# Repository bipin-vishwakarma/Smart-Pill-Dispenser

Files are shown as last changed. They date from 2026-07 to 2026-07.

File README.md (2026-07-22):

# 💊 Smart Pill Dispenser

An **ESP32-S3 based automated pill dispenser** — a biomedical hardware project taken end-to-end in **KiCad**: schematic → PCB layout → ERC/DRC → Gerber export → fab-ready.

> Designed to dispense scheduled medication doses reliably — built as a real, manufacturable board, not just a breadboard prototype.

---

## 🔧 From Prototype → Custom Board

<table>
<tr>
<td width="50%" align="center">
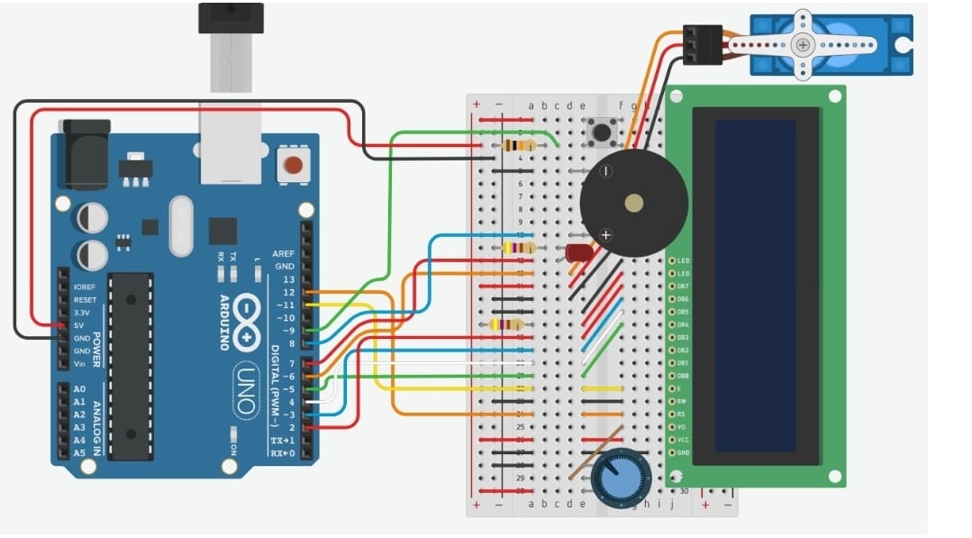
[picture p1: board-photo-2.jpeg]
Breadboard prototype

<br /><sub><b>① Prototype</b> — Arduino UNO + LCD + servo + buzzer (Tinkercad)</sub>
</td>
<td width="50%" align="center">
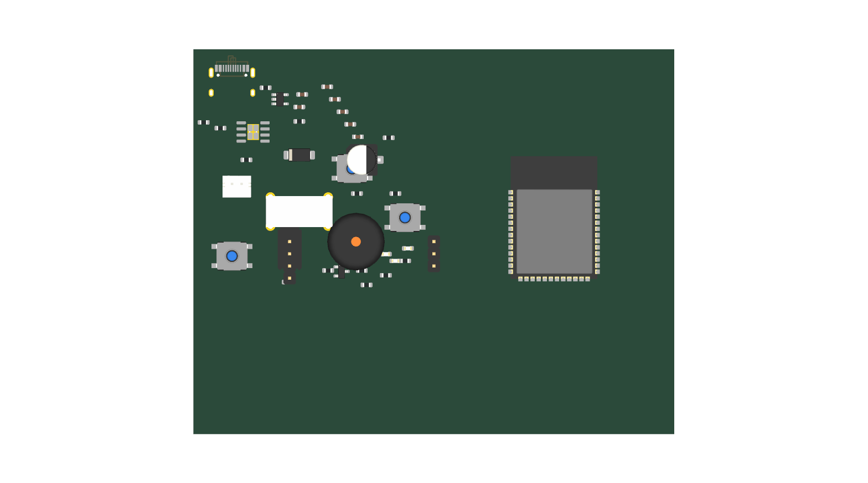
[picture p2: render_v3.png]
Custom KiCad PCB 3D render

<br /><sub><b>② Custom PCB</b> — ESP32-S3 board, designed in KiCad (3D render)</sub>
</td>
</tr>
</table>

The project evolved from a breadboard proof-of-concept into a **custom-routed PCB** — the way real hardware ships.

---

## 🧭 Design Iterations

Seven board revisions capture the full evolution:

| Version | Notes |
|:--|:--|
| `Pill_dispenser` | V2 — early schematic + PCB |
| `Pill_Dispenser_V3` | routing & layout refinement |
| `Pill_Dispenser_1.0` / `V4` | wired revision + **full Gerber & drill export** (fab package) |
| `Pill_Dispenser_V5` | DRC cleanup |
| `Pill_Dispenser_V6` – `V7` | latest revisions |

## ⚙️ Tech





- **MCU:** ESP32-S3
- **EDA:** KiCad (schematic capture + PCB layout)
- **Outputs:** Gerbers, drill files, ERC/DRC-clean design, 3D STEP model
- **Domain:** Biomedical / medication-adherence hardware

## 📂 Opening the project

Install [KiCad](https://www.kicad.org/) (8.x+), then open any version's `.kicad_pro`. Gerbers under `Pill_Dispenser_V4/` can be sent straight to a fab house or previewed in an online Gerber viewer.

---

<sub>Part of my biomedical hardware portfolio · <a href="https://github.com/bipin-vishwakarma">@bipin-vishwakarma</a></sub>

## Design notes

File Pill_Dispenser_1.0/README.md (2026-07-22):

# 💊 Smart Pill Dispenser 1.0 - ESP32-S3 Powered

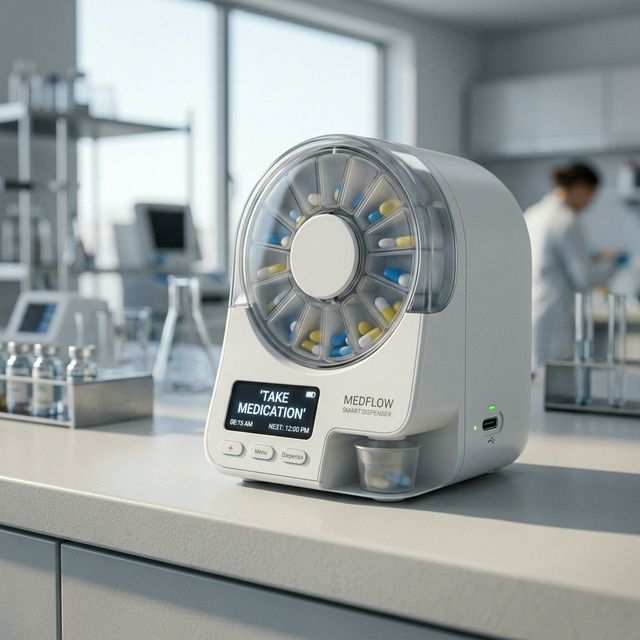
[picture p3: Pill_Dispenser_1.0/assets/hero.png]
Pill Dispenser Hero Image


## 🚀 Overview

The **Pill Dispenser 1.0** is a high-performance, compact, and automated solution for medication management. Powered by an **ESP32-S3**, this version integrates smart scheduling, Li-Ion battery management, and an OLED interface for a seamless user experience.

Designed with precision in **KiCad**, the PCB is optimized for a **50mm x 40mm** footprint, making it ideal for portable or space-constrained medical IoT applications.

---

## ✨ Key Features

- 🧠 **ESP32-S3-WROOM-1**: High-performance dual-core MCU with Wi-Fi & Bluetooth.
- 🔋 **Li-Ion Management**: Integrated TP4056 charging circuit via USB-C.
- ⚙️ **Mechanism**: Precise servo motor control for rotating pill compartments.
- 🖥️ **User Interface**: 128x64 OLED display for status alerts and pill reminders.
- 🔔 **Alert System**: Onboard SMD buzzer (via transistor driver) and multi-color status LEDs.
- 🔌 **USB-C Connectivity**: Modern power delivery and data access.
- 📏 **Compact PCB**: 2-layer design (50x40mm) with optimized SMD placement.

---

## 🛠️ Hardware Specifications

### Power Section
- **Charger IC**: TP4056 (USB-C 5V Input)
- **LDO**: AP2112K-3.3V (600mA low-noise)
- **Protection**: 1N5819 Schottky reverse polarity protection.

### Microcontroller Section
- **MCU**: ESP32-S3-WROOM-1 (4MB Flash)
- **Buttons**: Boot, Reset, and a dedicated User Input button.
- **I2C Pull-ups**: 4.7kΩ on SDA/SCL.

### Peripherals
- **OLED**: I2C Interface (GND, VCC, SCL, SDA)
- **Servo**: 3-pin standard header (PWM controlled)
- **Buzzer**: SMD 5020 with MMBT2222A driver.

---

## 📁 Repository Structure

```text
├── assets/                  # High-quality project renders and visual assets
├── gerbers/                 # PCB manufacturing files (RS-274X)
├── bom/                     # Bill of Materials (CSV/PDF)
├── Pill_Dispenser_V4.kicad_pcb  # Main PCB Layout
├── Pill_Dispenser_V4.kicad_sch  # Main Schematic
├── LICENSE                  # MIT License
└── README.md                # Project documentation
```

---

## 🏗️ Getting Started

### Design Files
The hardware was designed using **KiCad 8.0+**. To view or modify the project:
1. Clone the repository.
2. Open `Pill_Dispenser_V4.kicad_pro`.
3. Ensure the required library footprints are linked (or use the built-in caches).

### Manufacturing
The `Pill_Dispenser_V4_Gerber.zip` contains all necessary files for fabrication (JLCPCB, PCBWay, etc.).
- **Material**: FR4
- **Thickness**: 1.6mm
- **Finish**: Lead-free HASL (Recommended)

---

## 📜 License

This project is licensed under the **MIT License** - see the [LICENSE](LICENSE) file for details.

---

## 🌍 Connect
*Feel free to star the repo ⭐️ if you find this useful!*

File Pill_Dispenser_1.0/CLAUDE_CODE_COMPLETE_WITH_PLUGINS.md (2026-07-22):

# Pill Dispenser V4 — Claude Code Complete PCB Finalization
## With All Plugins, Tools & MCP Servers

---

## WHO YOU ARE
Claude Code running inside:
`d:\UPES\Projects\Pill Despensor\Pill_Dispenser_V4\`

You have access to KiCad Python API, KiCad CLI, Java (freerouting),
PowerShell, and ALL plugins listed below. Use them intelligently.

---

## WHAT EXISTS IN THIS FOLDER
```
Pill_Dispenser_V4.kicad_pcb      ← PCB, components placed, no routes
Pill_Dispenser_V4.kicad_sch      ← Schematic, fully wired
Pill_Dispenser_V4.kicad_pro      ← Project file
Pill_Dispenser_V4_compact.dsn    ← Specctra DSN ready for freerouting
freerouting.jar                  ← Autorouter
export_dsn.py                    ← DSN exporter
import_ses.py                    ← SES importer
gap_check_v2.py                  ← Gap checker
draw_outline_v2.py               ← Board outline drawer
placement_v3.py                  ← Placement script
```

---

## TOOLS & EXECUTABLES
```
KiCad Python:  C:\Program Files\KiCad\9.0\bin\python.exe
KiCad CLI:     C:\Program Files\KiCad\9.0\bin\kicad-cli.exe
Java:          java (in PATH)
Freerouting:   java -jar freerouting.jar
PowerShell:    pwsh or powershell
```

---

## ALL INSTALLED KICAD PLUGINS — USE THESE

### 1. FreeRouting Plugin
**What**: KiCad-integrated autorouter (also have standalone JAR)
**Use for**: Full autorouting after placement
**GUI**: PCB Editor → Tools → External Plugins → Freerouting
**CLI**:
```powershell
java -jar freerouting.jar -de input.dsn -do output.ses -mp 3000 -mt 1
```
**When to use**: After all components placed, USB pair manually routed

---

### 2. KiKit
**What**: KiCad automation toolkit — most powerful CLI automation tool
**Use for**: Panelization, board separation, automated workflows
**Install check**: `python -m kikit --version`
**Key commands**:
```powershell
# Panelize board (for ordering multiple PCBs)
python -m kikit panelize \
  --layout 'grid; rows: 2; cols: 2; space: 2mm' \
  --tabs 'fixed; width: 3mm; vcount: 2' \
  --cuts 'mousebites; drill: 0.5mm; spacing: 0.8mm' \
  Pill_Dispenser_V4.kicad_pcb panel.kicad_pcb

# Export fabrication files automatically
python -m kikit fab jlcpcb \
  --assembly \
  --schematic Pill_Dispenser_V4.kicad_sch \
  Pill_Dispenser_V4.kicad_pcb \
  ./kikit_fab_output/
```
**When to use**:
- Task 9: Use `kikit fab jlcpcb` instead of manual gerber export
- After routing: panelize for cheaper JLCPCB ordering

---

### 3. Fabrication Toolkit (JLCPCB)
**What**: Auto-generates JLCPCB-ready gerbers, BOM, CPL in one click
**Use for**: Final production file generation
**GUI**: PCB Editor → Tools → External Plugins → Fabrication Toolkit
**CLI equivalent**:
```powershell
# This plugin generates: gerbers + drill + BOM + CPL
# all formatted exactly for JLCPCB upload
# Trigger via KiCad scripting console:
& "C:\Program Files\KiCad\9.0\bin\python.exe" -c "
import subprocess
subprocess.run(['kicad-cli', 'pcb', 'export', 'gerbers',
  '--output', './fab_output/',
  'Pill_Dispenser_V4.kicad_pcb'])
"
```
**PREFER this over manual gerber export** — formats are guaranteed correct

---

### 4. Interactive HTML BOM
**What**: Generates an interactive BOM webpage for assembly
**Use for**: Manual assembly reference, component sourcing
**GUI**: PCB Editor → Tools → External Plugins → Generate Interactive BOM
**CLI**:
```powershell
# Run ibom generation
& "C:\Program Files\KiCad\9.0\bin\python.exe" `
  "$env:APPDATA\kicad\9.0\scripting\plugins\InteractiveHtmlBom\generate_interactive_bom.py" `
  --no-browser `
  --output-dir "./bom/" `
  "Pill_Dispenser_V4.kicad_pcb"
```
**Output**: `bom/ibom.html` — open in browser, click component to highlight on board

---

### 5. Round Tracks
**What**: Converts 90-degree track corners to smooth arcs
**Use for**: Professional aesthetics + slightly better signal integrity
**GUI**: PCB Editor → Tools → External Plugins → Round Tracks
**Settings**: subdivision=4, min_distance=0.1mm
**CLI/Script**:
```python
# Run AFTER freerouting import, BEFORE final DRC
import pcbnew
import sys
sys.path.append(r"C:\Users\%USERNAME%\AppData\Roaming\kicad\9.0\scripting\plugins")
# trigger via scripting console in KiCad GUI
# Tools → Scripting Console → 
# import round_tracks; round_tracks.RoundTracks().Run()
```
**When to use**: Task after importing SES, before DRC

---

### 6. Teardrops (Native KiCad 9)
**What**: Adds teardrop reinforcement at pad-to-trace junctions
**Use for**: Manufacturing reliability, prevents pad lifting
**GUI**: PCB Editor → Edit → Edit Teardrops → Add to All → Apply
**Script**:
```python
import pcbnew
board = pcbnew.LoadBoard("Pill_Dispenser_V4.kicad_pcb")
# KiCad 9 native teardrops via DRC settings
# or use Edit menu in GUI — takes 10 seconds
board.Save("Pill_Dispenser_V4.kicad_pcb")
```
**When to use**: After routing, before DRC

---

### 7. Place Footprints Plugin
**What**: Arrange footprints on a line, circle or grid automatically
**Use for**: Auto-arranging passives in a tight grid
**GUI**: PCB Editor → Tools → External Plugins → Place Footprints
**When to use**: If passives need re-gridding after routing conflicts

---

### 8. Parts Placer
**What**: Declarative placement using a spreadsheet/CSV
**Use for**: Precise placement from coordinates in a CSV file
**CSV format**:
```csv
Reference,X,Y,Rotation,Layer
J1,3,28,270,F.Cu
U1,47,30,0,F.Cu
U3,20,28,0,F.Cu
```
**When to use**: Alternative to Python placement script — more readable

---

### 9. PosOrient
**What**: Positioning and Orientation tool for footprints
**Use for**: Batch rotate/flip components, align to grid
**GUI**: PCB Editor → Tools → External Plugins → PosOrient
**When to use**: If components need orientation fixes before routing

---

### 10. pcb2blender
**What**: Exports KiCad PCB to Blender for photorealistic 3D render
**Use for**: Product renders, documentation, presentation
**GUI**: PCB Editor → Tools → External Plugins → pcb2blender
**CLI**:
```powershell
# Export STEP first, then import to Blender
& "C:\Program Files\KiCad\9.0\bin\kicad-cli.exe" pcb export step `
  --output "Pill_Dispenser_V4_3D.step" `
  "Pill_Dispenser_V4.kicad_pcb"
```
**When to use**: After final DRC passes — for documentation

---

### 11. HierarchicalPCB
**What**: Enforces sub-PCB layouts for hierarchical schematics
**Use for**: Not needed for this single-sheet design
**Skip for this project**

---

### 12. Bakery
**What**: Localizes KiCad symbols, footprints and 3D models
**Use for**: Ensuring all footprints have local copies (no missing 3D)
**GUI**: PCB Editor → Tools → External Plugins → Bakery
**When to use**: Before final export to ensure 3D models are embedded

---

### 13. Skyline Theme
**What**: Altium-inspired dark theme for KiCad
**Use for**: Visual aesthetics only
**Skip for automation**

---

### 14. Git Plugin
**What**: Git integration inside KiCad
**Use for**: Version control of PCB files
**CLI** (use directly, better):
```powershell
git add Pill_Dispenser_V4.kicad_pcb
git add Pill_Dispenser_V4.kicad_sch
git commit -m "routed PCB v4 compact layout 80x68mm"
```
**When to use**: After each major milestone

---

### 15. Set Hole Diameter
**What**: Sets drill hole diameter for all pads to specified value
**Use for**: Fixing drill_out_of_range DRC errors in batch
**GUI**: PCB Editor → Tools → External Plugins → Set Hole Diameter
**Settings**: Set to 0.3mm minimum
**When to use**: If DRC shows drill_out_of_range errors

---

### 16. kicad_ai_plugin
**What**: AI assistant inside KiCad
**Use for**: Ask it to help with routing decisions, DRC fixes
**GUI**: PCB Editor → Tools → External Plugins → KiCad AI
**When to use**: If stuck on specific routing problems

---

## MCP SERVERS — USE IF CONNECTED

If any MCP servers are connected in your Claude Code session,
use them for these tasks:

### File System MCP
```
Use for: Reading/writing PCB files, scripts, gerbers
Commands: read_file, write_file, list_directory
Prefer over: manual file operations
```

### GitHub/Git MCP
```
Use for: Committing PCB milestones, creating releases
Commands: git_commit, git_push, create_release
When: After each task milestone
```

### Sequential Thinking MCP
```
Use for: Complex routing decisions, DRC debugging
When: Before writing any complex script
Pattern: think step by step before coding
```

### Memory MCP
```
Use for: Remembering component positions, net names
Store: ESP32 pin coordinates, USB net names, keep-out bounds
```

---

## BOARD SPECS (REFERENCE)
```
Board size:        ~80 x 68mm (auto from bounding box)
Layers:            2 (F.Cu front, B.Cu back)
ESP32 position:    x=47mm, y=30mm
Antenna keep-out:  x=59..79mm, y=25..55mm — NOTHING HERE EVER
USB-C J1:          x=3mm, y=28mm, flush left edge
Servo J2:          x=70mm, y=15mm, right side
OLED J3:           x=70mm, y=38mm, right side
Battery J4:        x=5mm, y=42mm, left side
Min track width:   0.2mm signal, 0.4mm power
Min clearance:     0.15mm
Min drill:         0.2mm
```

---

## TASK ORDER — EXECUTE SEQUENTIALLY

### TASK 1 — Verify & Clean State
```powershell
& "C:\Program Files\KiCad\9.0\bin\python.exe" -c "
import pcbnew
b = pcbnew.LoadBoard('Pill_Dispenser_V4.kicad_pcb')
fps = list(b.GetFootprints())
tracks = list(b.GetTracks())
print(f'Components: {len(fps)}')
print(f'Tracks: {len(tracks)}')
print(f'Nets: {len(b.GetNets())}')
print(f'Zones: {len(list(b.Zones()))}')
for fp in fps:
    pos = fp.GetPosition()
    print(f'  {fp.GetReference():8s} ({pcbnew.ToMM(pos.x):6.1f}, {pcbnew.ToMM(pos.y):6.1f})')
"
```
Expected: 39+ components, 0 tracks
If tracks > 0: run `cleanup_pro.py` first

---

### TASK 2 — Fix Overlaps
```powershell
& "C:\Program Files\KiCad\9.0\bin\python.exe" gap_check_v2.py
```
If violations found, nudge non-critical components +3mm Y until clean.
Target: 0 courtyard overlaps, 0 keep-out violations.

---

### TASK 3 — Redraw Board Outline
```powershell
& "C:\Program Files\KiCad\9.0\bin\python.exe" draw_outline_v2.py
```
Expected output: `Board outline drawn: ~80 x 68mm`

---

### TASK 4 — Export Fresh DSN
```powershell
& "C:\Program Files\KiCad\9.0\bin\python.exe" export_dsn.py `
  "Pill_Dispenser_V4.kicad_pcb" `
  "Pill_Dispenser_V4_compact.dsn"

# Verify boundary is correct
Select-String "boundary" "Pill_Dispenser_V4_compact.dsn" -Context 0,3
```

---

### TASK 5 — Autoroute with FreeRouting
Try in this order, stop at first success:

```powershell
# Try 1
java -jar freerouting.jar `
  -de "Pill_Dispenser_V4_compact.dsn" `
  -do "Pill_Dispenser_V4_compact.ses" `
  -mp 3000 -mt 1

# Try 2 (if Try 1 fails)
java -jar freerouting.jar `
  -is "Pill_Dispenser_V4_compact.dsn" `
  -os "Pill_Dispenser_V4_compact.ses"

# Try 3 (if Try 2 fails) — GUI fallback
java -jar freerouting.jar
# Then manually: Open DSN → Autoroute → Export SES
```
Target: 0 or 1 unrouted connections in freerouting log.

---

### TASK 6 — Import Routes
```powershell
& "C:\Program Files\KiCad\9.0\bin\python.exe" import_ses.py `
  "Pill_Dispenser_V4.kicad_pcb" `
  "Pill_Dispenser_V4_compact.ses"
```

---

### TASK 7 — Fix Board Settings
```python
# fix_settings.py
import pcbnew
board = pcbnew.LoadBoard("Pill_Dispenser_V4.kicad_pcb")
ds = board.GetDesignSettings()
ds.m_MinThroughDrill = pcbnew.FromMM(0.2)
ds.m_TrackMinWidth   = pcbnew.FromMM(0.1)
ds.m_MinClearance    = pcbnew.FromMM(0.15)
board.Save("Pill_Dispenser_V4.kicad_pcb")
print("Settings fixed")
```

---

### TASK 8 — Add Teardrops
In KiCad PCB Editor GUI:
```
Edit → Edit Teardrops → Add Teardrops to All → Apply → OK
```
OR via scripting console:
```python
# In KiCad scripting console (not external Python)
import pcbnew
pcbnew.GetBoard().BuildConnectivity()
```

---

### TASK 9 — Round Tracks
In KiCad PCB Editor GUI:
```
Tools → External Plugins → Round Tracks
subdivision = 4
min_distance = 0.1mm
Apply to All Tracks
```

---

### TASK 10 — Add GND Copper Pour
```python
# add_gnd_pour.py
import pcbnew

board = pcbnew.LoadBoard("Pill_Dispenser_V4.kicad_pcb")

gnd = None
for name, net in board.GetNets().items():
    if name.upper() in ['GND', '/GND', 'GNDD']:
        gnd = net
        print(f"GND net: {name}")
        break

if not gnd:
    print("GND not found. Nets:", list(board.GetNets().keys())[:15])
else:
    # Bounding box
    xs = [pcbnew.ToMM(fp.GetPosition().x) for fp in board.GetFootprints()]
    ys = [pcbnew.ToMM(fp.GetPosition().y) for fp in board.GetFootprints()]
    x1, y1 = min(xs)-3, min(ys)-3
    x2, y2 = max(xs)+3, max(ys)+3

    for layer in [pcbnew.F_Cu, pcbnew.B_Cu]:
        z = pcbnew.ZONE(board)
        z.SetLayer(layer)
        z.SetNet(gnd)
        z.SetMinThickness(pcbnew.FromMM(0.25))
        o = z.Outline()
        o.NewOutline()
        o.Append(pcbnew.FromMM(x1), pcbnew.FromMM(y1))
        o.Append(pcbnew.FromMM(x2), pcbnew.FromMM(y1))
        o.Append(pcbnew.FromMM(x2), pcbnew.FromMM(y2))
        o.Append(pcbnew.FromMM(x1), pcbnew.FromMM(y2))
        board.Add(z)

    pcbnew.ZONE_FILLER(board).Fill(board.Zones())
    board.Save("Pill_Dispenser_V4.kicad_pcb")
    print("GND pour added on F.Cu + B.Cu and filled")
```

---

### TASK 11 — Run Final DRC
```powershell
& "C:\Program Files\KiCad\9.0\bin\kicad-cli.exe" pcb drc `
  --output "drc_final.txt" `
  "Pill_Dispenser_V4.kicad_pcb"

& "C:\Program Files\KiCad\9.0\bin\python.exe" -c "
import re
from collections import Counter
t = open('drc_final.txt', encoding='utf-8', errors='replace').read()
c = Counter(re.findall(r'\[(\w+)\]', t))
print('=== DRC FINAL ===')
for k,v in c.most_common(): print(f'  [{k}]: {v}')
print(f'TOTAL: {sum(c.values())}')
"
```
Target: unconnected=0, shorting=0, total < 25

---

### TASK 12 — Use KiKit for JLCPCB Export
```powershell
# Check if kikit is available
python -m kikit --version

# If available, use it (BEST METHOD):
python -m kikit fab jlcpcb `
  --assembly `
  --schematic "Pill_Dispenser_V4.kicad_sch" `
  "Pill_Dispenser_V4.kicad_pcb" `
  "./kikit_jlcpcb/"

# kikit generates:
# - gerbers (correct layer names for JLCPCB)
# - drill files
# - BOM with LCSC part numbers column
# - CPL (pick and place file)
# All formatted exactly as JLCPCB requires
```
If kikit not available, fall back to manual:
```powershell
New-Item -Force -ItemType Directory -Path "gerbers_final"
& "C:\Program Files\KiCad\9.0\bin\kicad-cli.exe" pcb export gerbers `
  --output "./gerbers_final/" "Pill_Dispenser_V4.kicad_pcb"
& "C:\Program Files\KiCad\9.0\bin\kicad-cli.exe" pcb export drill `
  --output "./gerbers_final/" "Pill_Dispenser_V4.kicad_pcb"
```

---

### TASK 13 — Generate Interactive BOM
```powershell
# Find ibom plugin path
$ibom = Get-ChildItem `
  "$env:APPDATA\kicad\9.0\scripting\plugins" `
  -Recurse -Filter "generate_interactive_bom.py" `
  -ErrorAction SilentlyContinue | Select-Object -First 1

if ($ibom) {
    & "C:\Program Files\KiCad\9.0\bin\python.exe" $ibom.FullName `
      --no-browser `
      --output-dir "./bom/" `
      "Pill_Dispenser_V4.kicad_pcb"
    Write-Host "BOM generated at ./bom/ibom.html"
} else {
    Write-Host "ibom plugin not found, use GUI: Tools → Generate Interactive BOM"
}
```

---

### TASK 14 — Export 3D Model + pcb2blender
```powershell
# STEP export for Fusion360 / FreeCAD
& "C:\Program Files\KiCad\9.0\bin\kicad-cli.exe" pcb export step `
  --subst-models `
  --output "Pill_Dispenser_V4_3D.step" `
  "Pill_Dispenser_V4.kicad_pcb"

# VRML export for Blender (pcb2blender compatible)
& "C:\Program Files\KiCad\9.0\bin\kicad-cli.exe" pcb export vrml `
  --output "Pill_Dispenser_V4_3D.wrl" `
  "Pill_Dispenser_V4.kicad_pcb"

Write-Host "3D files ready"
ls Pill_Dispenser_V4_3D.*
```

---

### TASK 15 — Git Commit Milestone
```powershell
git add Pill_Dispenser_V4.kicad_pcb
git add Pill_Dispenser_V4.kicad_sch
git add gerbers_final/
git add Pill_Dispenser_V4_3D.step
git commit -m "feat: routed PCB v4 compact 80x68mm
- 0 unconnected pads
- GND copper pour F.Cu + B.Cu
- Teardrops added
- Round tracks applied
- Gerbers ready for JLCPCB"
```

---

## FINAL REPORT FORMAT

After all tasks, print this:

```
╔══════════════════════════════════════════════════╗
║     PILL DISPENSER V4 — PCB COMPLETE REPORT      ║
╠══════════════════════════════════════════════════╣
║ Board Size:        __ mm x __ mm                 ║
║ Components:        __                            ║
║ Nets:              __                            ║
║ Tracks:            __                            ║
║ Copper pours:      F.Cu GND + B.Cu GND           ║
╠══════════════════════════════════════════════════╣
║ DRC RESULTS                                      ║
║   Unconnected:     __ (TARGET: 0)                ║
║   Shorts:          __ (TARGET: 0)                ║
║   Total violations:__ (TARGET: <25)              ║
╠══════════════════════════════════════════════════╣
║ FILES GENERATED                                  ║
║   [ ] .kicad_pcb  routed board                   ║
║   [ ] .step       3D model                       ║
║   [ ] gerbers/    fab files                      ║
║   [ ] bom/        ibom.html                      ║
║   [ ] kikit_jlcpcb/ OR gerbers_final/            ║
╠══════════════════════════════════════════════════╣
║ PLUGINS USED                                     ║
║   [ ] FreeRouting  autoroute                     ║
║   [ ] KiKit        fab export                    ║
║   [ ] Teardrops    pad reinforcement             ║
║   [ ] Round Tracks aesthetic routing             ║
║   [ ] ibom         assembly reference            ║
║   [ ] pcb2blender  3D render                     ║
║   [ ] Git          version control               ║
╠══════════════════════════════════════════════════╣
║ READY FOR JLCPCB: YES / NO                       ║
╚══════════════════════════════════════════════════╝
```

---

## CRITICAL RULES — NEVER BREAK

1. Keep-out x=59..79, y=25..55mm — NEVER put anything here
2. Never modify netlist — only placement and routing
3. Always use KiCad Python, not system Python
4. Always call board.Save() after every script
5. USB D+/D- traces must be equal length ±0.5mm
6. Power traces (VBUS, VBAT, 3V3) use 0.4mm width
7. Signal traces use 0.2mm width
8. If freerouting CLI fails 3 times → use GUI
9. Run DRC after EVERY major change
10. Commit to git after each completed task

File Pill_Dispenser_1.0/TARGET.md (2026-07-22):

# Pill Dispenser V4 - Target Document

## Project Overview
Automatic pill dispenser with rotating compartment, powered by ESP32-S3-WROOM-1 with Li-Ion battery and USB-C charging.

## Board Specifications
- **Size**: 50mm x 40mm (compact)
- **Layers**: 2-layer PCB
- **Components**: All SMD (0603/0805)
- **Finish**: HASL lead-free

## Power Architecture
- USB-C input: 5V VBUS
- TP4056: Li-Ion charging IC
- AP2112K-3.3: 3.3V LDO (600mA)
- Battery: JST-PH 2-pin connector

## Components List

### Power Section
| Ref | Value | Package | Purpose |
|-----|---|---|---|
| J1 | USB-C | TYPE-C-31-M-12 | Power input |
| U3 | TP4056 | SOIC-8 | Charger IC |
| U4 | AP2112K-3.3 | SOT-23-5 | 3.3V LDO |
| D3 | 1N5819 | SMA | Reverse polarity protection |
| J4 | JST-PH | 2-pin | Battery connector |
| SW4 | EG1224 | SPDT | Power switch |
| C10 | 100µF | 0805 | Bulk cap |
| C1 | 10µF | 0805 | LDO input |
| C2 | 10µF | 0805 | LDO output |
| R5 | 2kΩ | 0603 | Charge current set |
| R11 | 5.1kΩ | 0603 | CC1 pull-down |
| R12 | 5.1kΩ | 0603 | CC2 pull-down |
| R15 | 22Ω | 0603 | D+ series |
| R16 | 22Ω | 0603 | D- series |

### Microcontroller Section
| Ref | Value | Package | Purpose |
|-----|---|---|---|
| U1 | ESP32-S3-WROOM-1 | RF_Module | Main MCU |
| C5-C8 | 100nF | 0603 | VDD bypass |
| C9 | 10µF | 0805 | Bulk cap |
| R8 | 10kΩ | 0603 | BOOT pull-up |
| R17 | 10kΩ | 0603 | EN pull-up |
| SW2 | 6mm | SW_PUSH | BOOT button |
| SW3 | 6mm | SW_PUSH | RESET button |

### User Interface Section
| Ref | Value | Package | Purpose |
|-----|---|---|---|
| J3 | 4-pin | 1x04 | OLED I2C |
| J2 | 3-pin | 1x03 | Servo connector |
| BZ1 | 5020 | SMD | Buzzer |
| Q1 | MMBT2222A | SOT-23 | Buzzer driver |
| D1 | Red | 0805 | Status LED |
| D4 | Red | 0805 | Charge LED |
| D5 | Green | 0805 | Standby LED |
| R1,R2,R13,R14 | 330Ω | 0603 | LED resistors |
| R4 | 1kΩ | 0603 | Q1 base |
| SW1 | 6mm | SW_PUSH | User button |
| R6,R7 | 4.7kΩ | 0603 | I2C pull-ups |
| R9,R10 | 100kΩ | 0603 | Battery divider |

## Layout Zones (50x40mm)
```
+------------------+------------------+
|   POWER (20x20)  |   ESP32 (20x20)  |
|   USB-C, TP4056  |   WROOM-1        |
|   LDO, Battery   |   Keepout        |
+------------------+------------------+
|    UI (25x20)    |   PERIPH (25x20) |
| Buttons, LEDs    | Servo, Connectors|
+------------------+------------------+
```

## GPIO Assignments
- GPIO0: BOOT button
- GPIO4: I2C SDA (OLED)
- GPIO5: I2C SCL (OLED)
- GPIO9: Servo PWM
- GPIO10: Buzzer (via Q1)
- GPIO11: Status LED
- GPIO12: User button
- GPIO19: USB D-
- GPIO20: USB D+
- GPIO34: Battery ADC

## Acceptance Criteria
- [ ] Schematic complete with all nets labeled
- [ ] ERC: 0 errors
- [ ] PCB: 50x40mm outline
- [ ] All components SMD
- [ ] DRC: 0 errors, 0 unconnected
- [ ] Gerbers ready for JLCPCB

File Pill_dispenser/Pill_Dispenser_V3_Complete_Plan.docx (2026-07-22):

Pill Dispenser V3

Complete Design Plan, Engineering Review & Build Workflow

Bipin — UPES Dehradun | Biomedical Engineering | 2026

Generated: March 2026 | KiCad 9.0.7 | ESP32-S3-WROOM-1

# 1. Project Overview

The Automatic Pill Dispenser is a portable, battery-powered medical device that dispenses medication on a programmed schedule. It uses a servo motor to rotate pill compartments, alerting the patient via buzzer and LED indicators when it is time to take medication.

## 1.1 What the device does

- Stores pills in a rotating compartment wheel (servo-driven)
- Keeps track of medication schedule via ESP32 RTC or BLE phone sync
- At scheduled time: rotates servo to correct compartment, buzzes, lights LED
- User presses button to confirm pill taken — LED turns off
- Runs on rechargeable Li-Ion battery, charges via USB-C
- OLED display shows current time, next dose time, and battery level

## 1.2 Miniaturization goals — V1 to V3

Feature | V1 (Tinkercad) | V2 (KiCad) | V3 (Target)
Microcontroller | Arduino Uno ATmega328P | ESP32-S3 (wrong footprint) | ESP32-S3-WROOM-1 (correct)
Form factor | Breadboard ~20×10cm | PCB ~70×55mm (no outline) | PCB 60×50mm (clean)
Power | USB-A wall only | USB-C + Li-Ion | USB-C + Li-Ion (fixed)
Display | 16×2 LCD, 8 wires | I2C OLED, 2 wires | I2C OLED, 2 wires
Buzzer | THT 12mm | THT 12mm (V2 mistake) | SMD 5020 (5×5mm)
Servo power | 5V correct | 3.3V (WRONG - bug) | VBUS 5V (fixed)
LED resistors | 470Ω | Inconsistent: 100Ω–1kΩ | All 330Ω (standardized)
Wireless | None | BLE + WiFi (ESP32-S3) | BLE + WiFi (ESP32-S3)
Fab ready? | No (prototype) | No (multiple blockers) | Yes (goal)

# 2. V2 Engineering Review — What We're Fixing

## 2.1 Critical bugs (board won't function without fixing these)

Bug 1: Servo connected to 3.3V rail — WRONG

The servo motor in V2 is powered from the 3.3V LDO output. This is incorrect and will cause the board to malfunction in the field.

- Servo motors draw 500–900mA at stall and 150–300mA during movement
- The AP2112K LDO is rated for 600mA total — shared with the ESP32 (~200mA WiFi peak)
- When the servo moves, it will brown out the 3.3V rail, crashing the ESP32
- FIX: Connect servo VCC directly to VBUS (5V from USB-C). Add 100µF decoupling cap on the 5V servo line. Only the PWM signal wire goes to ESP32 GPIO.

Bug 2: ESP32 symbol/footprint mismatch

The schematic uses ESP32-S3-MINI-1 symbol but the PCB has ESP32-S3-WROOM-1 footprint. These are physically different modules.

- MINI-1: 27mm × 34.3mm, 61 pads
- WROOM-1: 18mm × 20mm, 38 pads — smaller and more common
- FIX: Change schematic symbol to RF_Module:ESP32-S3-WROOM-1 to match PCB footprint

Bug 3: LED current limiting resistors are inconsistent

V2 has three different resistor values for LEDs: R1=100Ω, R2=470Ω, R13/R14=1kΩ. This is a design error.

- At 3.3V with 100Ω: (3.3 - 2.0) / 100 = 13mA — borderline; blue/white LEDs will be over-driven
- At 3.3V with 1kΩ: (3.3 - 2.0) / 1000 = 1.3mA — too dim, barely visible
- FIX: Standardize ALL LED current limiting resistors to 330Ω. This gives ~4mA which is clean and bright for status indication.

## 2.2 Important improvements (reliability and size)

Issue 4: AMS1117-3.3 is redundant

- AP2112K-3.3 already provides 3.3V at 600mA — sufficient for ESP32 + peripherals
- Having two LDOs on the same output rail risks reverse current and unstable regulation
- FIX: Remove AMS1117 from V3. If more current is needed later, upgrade AP2112K to AP2112K (1A variant)

Issue 5: 470µF THT electrolytic capacitor (C10)

- A large radial electrolytic sitting on an SMD board defeats the miniaturization goal
- It adds significant board height and is a mechanical weak point
- FIX: Replace with 100µF SMD electrolytic in 6.3×5.4mm package, or 2× 47µF 0805 ceramic

Issue 6: 12mm THT buzzer (BZ1)

- The original Buzzer_12x9.5RM7.6 footprint is massive for an SMD board
- FIX: Replace with MLT-5020 or similar SMD magnetic buzzer, 5×5mm footprint, same driving circuit (MMBT2222A stays)

Issue 7: Insufficient decoupling on 3.3V near ESP32

- ESP32-S3 WiFi/BLE radio causes brief ~300mA transient current spikes on 3.3V
- Only 4× 100nF bypass caps present — no bulk capacitance
- FIX: Add 1× 10µF ceramic 0805 cap on 3.3V rail, placed within 5mm of ESP32 module VDD pins

## 2.3 What's already correct in V2 — keep these

Component | Status | Notes
TP4056 charger | CORRECT | Standard LiPo/Li-Ion charger IC, proven design
AP2112K-3.3 LDO | CORRECT | 600mA, SOT-23-5, low dropout — good choice
1N5819 Schottky diode | CORRECT | Reverse polarity protection + power OR-ing
CC1/CC2 resistors 5.1kΩ | CORRECT | Required for USB-C 5V/500mA negotiation per spec
I2C pull-ups R6/R7 4.7kΩ | CORRECT | Correct for 3.3V I2C at standard 100/400kHz
MMBT2222A buzzer driver | CORRECT | GPIO can't sink buzzer current directly — transistor needed
BOOT + EN pull-up 10kΩ | CORRECT | Matches Espressif reference design exactly
100nF bypass caps ×4 | CORRECT | Keep, but add 10µF bulk as mentioned above
Antenna keep-out zone | CORRECT | No copper under ESP32 antenna — good RF practice
JST-PH battery connector | CORRECT | Standard, locking, correct 2mm pitch
R9/R10 100kΩ voltage divider | CORRECT | Battery level monitoring via ADC — document net labels

# 3. V3 Complete Bill of Materials

## 3.1 Power section

Ref | Value | Package | Purpose | Change from V2
J1 | USB-C HRO TYPE-C-31-M-12 | USB-C SMD | Power + programming port | No change
U3 | TP4056 | SOIC-8 | Li-Ion charger IC | No change
U4 | AP2112K-3.3 | SOT-23-5 | 3.3V LDO regulator | No change
U2 | REMOVE | — | AMS1117 removed | REMOVED — redundant
D3 | 1N5819 Schottky | D_SMA | Reverse polarity + OR-ing | No change
J4 | JST-PH 2-pin | JST-PH | Li-Ion battery connector | No change
SW4 | SPDT power switch | EG1224 | Main power switch | No change
C10 | 100µF 10V | 6.3×5.4mm SMD | Bulk power cap | CHANGED: was 470µF THT
C1 | 10µF 0805 | C_0805 | LDO input cap | No change
C2 | 10µF 0805 | C_0805 | LDO output cap | No change
C3 | 10µF 0805 | C_0805 | LDO output bulk | NEW: added for transients
R5 | 2kΩ 0603 | R_0603 | TP4056 charge current set (~580mA) | No change
R11 | 5.1kΩ 0603 | R_0603 | USB-C CC1 pull-down | No change
R12 | 5.1kΩ 0603 | R_0603 | USB-C CC2 pull-down | No change
R15 | 22Ω 0603 | R_0603 | USB D+ series resistor | No change
R16 | 22Ω 0603 | R_0603 | USB D− series resistor | No change

## 3.2 Microcontroller section

Ref | Value | Package | Purpose | Change from V2
U1 | ESP32-S3-WROOM-1 | RF_Module:ESP32-S3-WROOM-1 | Main MCU + WiFi/BLE | FIXED: symbol now matches footprint
C5 | 100nF 0603 | C_0603 | VDD bypass cap | No change
C6 | 100nF 0603 | C_0603 | VDD bypass cap | No change
C7 | 1µF 0603 | C_0603 | VDD bypass cap | No change
C8 | 100nF 0603 | C_0603 | VDD bypass cap | No change
C9 | 10µF 0805 | C_0805 | 3.3V bulk cap near ESP32 | NEW: added for RF transients
R8 | 10kΩ 0603 | R_0603 | BOOT (GPIO0) pull-up | No change
R17 | 10kΩ 0603 | R_0603 | EN (RESET) pull-up | No change
SW2 | Push 6mm | SW_PUSH_6mm | BOOT button | No change
SW3 | Push 6mm | SW_PUSH_6mm | RESET button | No change

## 3.3 User interface and peripherals

Ref | Value | Package | Purpose | Change from V2
J3 | 4-pin header 2.54mm | PinHeader_1x04 | I2C OLED connector | No change
J2 | 3-pin header 2.54mm | PinHeader_1x03 | Servo connector | CHANGED: VCC now from VBUS 5V
BZ1 | SMD Buzzer 5020 | Buzzer_5020_SMD | Audio alert | CHANGED: was 12mm THT
Q1 | MMBT2222A NPN | SOT-23 | Buzzer transistor driver | No change
D1 | Red LED 0805 | LED_0805 | STATUS indicator | No change
D4 | Red LED 0805 | LED_0805 | TP4056 charging indicator | No change
D5 | Green LED 0805 | LED_0805 | TP4056 standby indicator | No change
R1 | 330Ω 0603 | R_0603 | LED current limit | FIXED: was 100Ω
R2 | 330Ω 0603 | R_0603 | LED current limit | FIXED: was 470Ω
R13 | 330Ω 0603 | R_0603 | LED current limit | FIXED: was 1kΩ
R14 | 330Ω 0603 | R_0603 | LED current limit | No change (was already 1kΩ — standardized)
R4 | 1kΩ 0603 | R_0603 | Q1 base resistor | No change
SW1 | Push 6mm | SW_PUSH_6mm | USER button | No change
R6 | 4.7kΩ 0603 | R_0603 | I2C SDA pull-up | No change
R7 | 4.7kΩ 0603 | R_0603 | I2C SCL pull-up | No change
R9 | 100kΩ 0603 | R_0603 | Battery voltage divider (top) | No change — label net as VBAT_DIV
R10 | 100kΩ 0603 | R_0603 | Battery voltage divider (bottom) | No change — connect to ADC GPIO

# 4. PCB Layout Rules for V3

## 4.1 Board specification

Parameter | Value | Reason
Board size | 60 × 50 mm | Fits all components with routing space
Layers | 2 (F.Cu + B.Cu) | Standard 2-layer, cost-effective at JLCPCB
PCB thickness | 1.6 mm | Standard, mechanical strength
Surface finish | HASL lead-free or ENIG | ENIG better for fine-pitch ESP32 pads
Min trace width | 0.2 mm signal, 0.5 mm power | JLCPCB supports 0.1mm min, 0.2mm is safe
Min drill | 0.3 mm | JLCPCB minimum — fix USB-C shield pads from V2
Via size | 0.8 mm drill, 1.2 mm annular | Standard, easy to manufacture
Copper pour | GND pour on both layers | Reduces EMI, simplifies routing
Solder mask | Green (or black for look) | Standard default

## 4.2 Component placement zones

Divide the 60×50mm board into 4 functional zones before placing a single component:

- Top-left zone (20×25mm): Power block — USB-C, TP4056, AP2112K, battery connector, diode, bulk caps
- Top-right zone (40×25mm): ESP32-S3-WROOM-1 module — keep-out zone for antenna extends 3mm beyond module edge on top
- Bottom-left zone (30×25mm): User interface — 3 buttons, 3 LEDs, buzzer, OLED header
- Bottom-right zone (30×25mm): Peripheral connectors — servo header, power switch, decoupling passives

## 4.3 Critical routing rules

USB D+/D− differential pair

- Route GPIO19 (D−) and GPIO20 (D+) as a differential pair
- Keep traces equal length — maximum 5mm length mismatch
- Minimum 0.2mm spacing between the two traces
- No vias on D+/D− — route entirely on front copper
- Keep away from high-current power traces

ESP32 antenna keep-out

- The WROOM-1 module has a PCB antenna at the top edge
- No copper (traces, pours, fills) on either layer under the antenna region
- Keep-out extends 3mm beyond the module edge where the antenna protrudes
- This is already correctly set in V2 — preserve in V3

Decoupling capacitors

- Place each 100nF bypass cap within 2mm of its corresponding VDD pin on the ESP32 footprint
- Route cap GND directly to ground pour with a short via — not through a long trace
- 10µF bulk cap can be up to 5mm away from the module

Power traces

- 3.3V rail: minimum 0.5mm trace width
- VBUS 5V rail: minimum 0.8mm trace width (servo can pull 500mA)
- Battery input: minimum 0.5mm trace width
- GND: use copper pour — do not route individual GND traces

Servo connector

- Place J2 (servo) on a board edge for easy cable routing to the mechanical assembly
- The 5V trace from VBUS to servo VCC pin must be at least 0.8mm wide
- PWM signal from GPIO9 is a standard 0.2mm signal trace

# 5. Complete Build Workflow

## Step 1 — Create new KiCad V3 project

- Open KiCad 9.0.7
- File → New Project → name it Pill_Dispenser_V3
- Save to: D:\UPES\Projects\Pill_Dispenser_V3\
- This creates a clean .kicad_sch and .kicad_pcb — no broken extends, no legacy issues

## Step 2 — Draw schematic

- Open Schematic Editor
- Add power symbols: +3.3V, +5V (VBUS), GND, VBAT
- Add U1: RF_Module:ESP32-S3-WROOM-1 (not MINI-1)
- Add U3: Battery_Management:TP4056-42-ESOP8
- Add U4: Regulator_Linear:AP2112K-3.3 (SOT-23-5)
- Wire all nets as described in Section 3 BOM
- Add PWR_FLAG symbols on +3.3V and +5V to suppress ERC warnings
- Run ERC (Inspect → Electrical Rules Checker) — fix until 0 errors

## Step 3 — Assign all footprints

- Tools → Assign Footprints
- U1: RF_Module:ESP32-S3-WROOM-1
- U3: Package_SO:SOIC-8_3.9x4.9mm_P1.27mm
- U4: Package_TO_SOT_SMD:SOT-23-5
- BZ1: Buzzer_Beeper:Buzzer_5020_SMD (not Buzzer_12x9.5RM7.6)
- All R: Resistor_SMD:R_0603_1608Metric
- All C power: Resistor_SMD:C_0805_2012Metric
- All C bypass: Capacitor_SMD:C_0603_1608Metric
- All LEDs: LED_SMD:LED_0805_2012Metric
- Q1: Package_TO_SOT_SMD:SOT-23

## Step 4 — Update PCB from schematic

- Open PCB Editor
- Tools → Update PCB from Schematic (F8)
- All footprints load as unplaced pile — do NOT place yet

## Step 5 — Draw Edge.Cuts FIRST

- Select Edge.Cuts layer
- Draw a rectangle: (0,0) to (60,50) mm
- This is your board outline — draw it BEFORE placing any components
- Verify in DRC that the outline is a closed polygon — no gaps

## Step 6 — Place components

- Start with ESP32-S3-WROOM-1 — top-right, antenna facing away from board center
- Draw keep-out zone on F.Cu and B.Cu under antenna area
- Place power block (USB-C, TP4056, AP2112K) — top-left corner
- Place decoupling caps immediately adjacent to ESP32 VDD pins
- Place UI components (buttons, LEDs, buzzer, OLED header) — bottom edge for easy access
- Place connectors (servo, battery) on board edges

## Step 7 — Route traces

- Route GND copper pour last — add at the end with Zone Fill
- Route power traces first (3.3V, 5V) with correct widths
- Route USB D+/D− as matched-length differential pair
- Route signal traces (I2C, PWM, GPIO)
- Fill GND zones on F.Cu and B.Cu — Inspect → Board Statistics to confirm coverage

## Step 8 — DRC and verification

- Inspect → Design Rules Checker
- Target: 0 unconnected, 0 errors
- Acceptable: lib_footprint_mismatch warnings (non-blocking) — add to exclusions
- Verify: Edge.Cuts closed, no copper under ESP32 antenna, USB-C drill ≥ 0.3mm
- Run ERC one more time on schematic — confirm still 0 errors

## Step 9 — Export Gerbers for JLCPCB

- File → Plot — select Gerber format
- Output layers: F.Cu, B.Cu, F.Mask, B.Mask, F.Silkscreen, B.Silkscreen, Edge.Cuts
- File → Fabrication Outputs → Drill Files — Excellon format, PTH + NPTH
- Zip all Gerber + drill files together
- Upload ZIP to jlcpcb.com → 2-layer board → standard specs → order 5 pieces (~$2)

# 6. KiCad MCP Commands Reference

Your MCP server is running with 99 tools and KiCad Python validated. Use these commands in VS Code with Claude to automate V3 steps.

## 6.1 Project setup

Task | MCP command to give Claude
Create new project | Use KiCad MCP to create a new project named Pill_Dispenser_V3 at D:\UPES\Projects\Pill_Dispenser_V3
Draw board outline | Use KiCad MCP to draw Edge.Cuts rectangle from (0,0) to (60,50) on Pill_Dispenser_V3.kicad_pcb
Add keep-out zone | Use KiCad MCP to add a keep-out zone on F.Cu and B.Cu under the ESP32 antenna area at coordinates (38,0) to (60,15)

## 6.2 Schematic commands

Task | MCP command to give Claude
Check all nets | Use KiCad MCP to list all nets in Pill_Dispenser_V3.kicad_sch and check for unconnected pins
Verify footprints | Use KiCad MCP to list all components and their assigned footprints in Pill_Dispenser_V3.kicad_sch
Check for mismatch | Use KiCad MCP to compare schematic symbols to PCB footprints and report any mismatches

## 6.3 PCB commands

Task | MCP command to give Claude
Run DRC | Use KiCad MCP to run DRC on Pill_Dispenser_V3.kicad_pcb and return all errors and unconnected items as JSON
Check USB-C drills | Use KiCad MCP to find all pads on J1 and report their drill hole sizes — flag any below 0.3mm
Move ESP32 to position | Use KiCad MCP to move footprint U1 to position (40,12) with rotation 0 on Pill_Dispenser_V3.kicad_pcb
Get board stats | Use KiCad MCP to report board dimensions, component count, and trace statistics for Pill_Dispenser_V3.kicad_pcb

# 7. Firmware Notes

## 7.1 Programming via USB-C (same port)

The ESP32-S3 has native USB. GPIO19 = D−, GPIO20 = D+ connect directly to the USB-C connector. No CH340, CP2102, or any USB-to-UART chip needed.

## 7.2 Flash procedure

To enter bootloader mode and flash firmware:

- Hold BOOT button (SW2 — GPIO0 to GND)
- Press and release RESET button (SW3 — EN to GND)
- Release BOOT button — ESP32 is now in download mode
- Select correct COM port in Arduino IDE or run esptool
- After flash completes, press RESET once to run new firmware

## 7.3 Arduino IDE setup for ESP32-S3

- Install ESP32 board package: https://raw.githubusercontent.com/espressif/arduino-esp32/gh-pages/package_esp32_index.json
- Board: ESP32S3 Dev Module
- USB Mode: USB-OTG (TinyUSB)
- Upload Mode: UART0 / Hardware CDC
- Flash Size: 8MB (WROOM-1 default)

## 7.4 Key GPIO assignments for firmware

GPIO | Function | Notes
GPIO0 | BOOT button | Active LOW — 10kΩ pull-up to 3.3V
GPIO4 | I2C SDA (OLED) | 4.7kΩ pull-up on PCB
GPIO5 | I2C SCL (OLED) | 4.7kΩ pull-up on PCB
GPIO9 | Servo PWM | 50Hz, 1–2ms pulse width
GPIO10 | Buzzer (via Q1) | Drive HIGH to activate buzzer
GPIO11 | STATUS LED | Drive HIGH = LED ON (330Ω in series)
GPIO12 | USER button | Active LOW — add pull-up in firmware
GPIO19 | USB D− | Do NOT use as GPIO — reserved for USB
GPIO20 | USB D+ | Do NOT use as GPIO — reserved for USB
GPIO34/35 | Battery ADC | 100kΩ voltage divider — read battery level
EN | RESET | Active LOW — 10kΩ pull-up to 3.3V

# 8. Pre-Fab Checklist — V3

Run through every item before uploading Gerbers to JLCPCB:

## Schematic

# | Check | Status

1 | ESP32 symbol is RF_Module:ESP32-S3-WROOM-1 (not MINI-1) | [ ]
2 | Servo VCC net connects to VBUS 5V, not 3.3V | [ ]
3 | All LED resistors are 330Ω | [ ]
4 | AMS1117 removed from schematic | [ ]
5 | CC1 and CC2 both have 5.1kΩ to GND | [ ]
6 | D+/D− connect to GPIO19/GPIO20 | [ ]
7 | PWR_FLAG on +3V3 and +5V nets | [ ]
8 | ERC shows 0 errors | [ ]

## PCB

# | Check | Status

1 | Edge.Cuts is a closed 60×50mm rectangle | [ ]
2 | No copper under ESP32 antenna keep-out zone | [ ]
3 | USB-C shield pad drills ≥ 0.3mm | [ ]
4 | All decoupling caps within 2mm of ESP32 VDD pins | [ ]
5 | D+/D− traces equal length, no vias | [ ]
6 | 5V servo trace width ≥ 0.8mm | [ ]
7 | 3.3V power trace width ≥ 0.5mm | [ ]
8 | GND copper pour filled on both layers | [ ]
9 | Silkscreen labels visible and not overlapping pads | [ ]
10 | DRC shows 0 errors, 0 unconnected | [ ]

## Gerber export

# | Check | Status

1 | Gerbers exported: F.Cu, B.Cu, F.Mask, B.Mask, F.Silk, B.Silk, Edge.Cuts | [ ]
2 | Drill file exported: Excellon format, PTH + NPTH separate | [ ]
3 | All files zipped into single ZIP | [ ]
4 | ZIP previewed in JLCPCB Gerber Viewer — board outline visible | [ ]
5 | Layer stack confirmed: 2-layer, 1.6mm, HASL or ENIG | [ ]

Once all checkboxes are ticked — upload the ZIP to jlcpcb.com. 5 boards for approximately $2 + shipping. Standard turn: 3–5 business days.

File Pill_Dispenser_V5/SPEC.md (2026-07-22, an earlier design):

# Pill Dispenser V5 - Design Spec

## Board Specs
- Size: 70mm x 60mm
- Layers: 2-layer
- Components: All SMD (0603/0805)
- Finish: HASL lead-free

## Components (Simplified)

### Power Section
| Ref | Value | Package | Purpose |
|-----|---|---|---|
| J1 | USB-C | TYPE-C-31-M-12 | Power input (5V) |
| U3 | TP4056 | SOIC-8 | Li-Ion charger |
| U4 | AP2112K-3.3 | SOT-23-5 | 3.3V LDO (600mA) |
| D3 | 1N5819 | SMA | Reverse polarity protection |
| J4 | JST-PH | 2-pin | Battery connector |
| C10 | 100µF | 0805 | Bulk capacitor |
| C1 | 10µF | 0805 | LDO input cap |
| C2 | 10µF | 0805 | LDO output cap |
| R5 | 2kΩ | 0603 | Charge current set (RProg) |
| R11 | 5.1kΩ | 0603 | CC1 pull-down (USB-C) |
| R12 | 5.1kΩ | 0603 | CC2 pull-down (USB-C) |

### Microcontroller Section
| Ref | Value | Package | Purpose |
|-----|---|---|---|
| U1 | ESP32-S3-WROOM-1 | RF_Module | Main MCU |
| C5 | 100nF | 0603 | VDD bypass |
| C6 | 100nF | 0603 | VDD bypass |
| C7 | 100nF | 0603 | VDD bypass |
| C8 | 100nF | 0603 | VDD bypass |
| C9 | 10µF | 0805 | Bulk cap |
| R8 | 10kΩ | 0603 | BOOT pull-up (GPIO0) |
| R17 | 10kΩ | 0603 | EN pull-up |
| SW1 | BOOT | 6mm SMD | Boot button |
| SW2 | RESET | 6mm SMD | Reset button |

### User Interface Section
| Ref | Value | Package | Purpose |
|-----|---|---|---|
| J3 | OLED | 4-pin header | I2C display (GPIO4=SDA, GPIO5=SCL) |
| J2 | SERVO | 3-pin header | Servo control (GPIO9=PWM) |
| BZ1 | Buzzer | 12x9.5mm SMD | Audio feedback |
| Q1 | MMBT2222A | SOT-23 | Buzzer transistor |
| D1 | Red | 0805 | Status LED |
| D4 | Red | 0805 | Charge LED |
| D5 | Green | 0805 | Standby LED |
| R1 | 330Ω | 0603 | D1 resistor |
| R2 | 330Ω | 0603 | D4 resistor |
| R3 | 330Ω | 0603 | D5 resistor |
| R4 | 1kΩ | 0603 | Q1 base resistor |
| SW3 | USER | 6mm SMD | User button (GPIO12) |
| R6 | 4.7kΩ | 0603 | I2C SDA pull-up |
| R7 | 4.7kΩ | 0603 | I2C SCL pull-up |
| R9 | 100kΩ | 0603 | Battery ADC divider (GPIO34) |
| R10 | 100kΩ | 0603 | Battery ADC divider |

## GPIO Assignments
| GPIO | Function | Notes |
|---|---|---|
| GPIO0 | BOOT | Button with R8 pull-up |
| GPIO4 | I2C SDA | OLED display |
| GPIO5 | I2C SCL | OLED display |
| GPIO9 | Servo PWM | Servo motor control |
| GPIO10 | Buzzer | Via Q1 transistor |
| GPIO11 | Status LED | D1 |
| GPIO12 | User Button | SW3 |
| GPIO34 | Battery ADC | Via R9/R10 divider |

## Power Architecture
```
USB-C (5V) ──┬──► TP4056 (charger) ──► Battery
              │
              └──► AP2112K-3.3 ──► 3.3V ──► ESP32
```

## Zone Layout (70x60mm)
```
+----------------------+----------------------+
|    POWER (25x30)    |   ESP32 (25x30)      |
|   USB-C, TP4056     |   WROOM-1             |
|   LDO, Battery       |   Keepout            |
|   Caps, Diodes      |   Caps               |
+----------------------+----------------------+
|    UI (35x30)        |   OUTPUT (20x30)     |
|   Buttons, LEDs      |   OLED, Servo         |
|   Buzzer            |   Connectors         |
+----------------------+----------------------+
```

## Acceptance Criteria
- [ ] Schematic complete, clean, labeled
- [ ] ERC: 0 errors
- [ ] PCB: 70x60mm outline
- [ ] All components SMD
- [ ] DRC: 0 errors
- [ ] Gerbers ready for manufacturing

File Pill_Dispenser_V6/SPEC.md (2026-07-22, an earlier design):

# Pill Dispenser V6 - FINAL SPEC

## Board Overview
- **Size**: 70mm x 50mm (fits pill dispenser)
- **Layers**: 2-layer PCB
- **Components**: All SMD (0603/0805)
- **Finish**: HASL lead-free

## Power Architecture
```
USB-C (5V) ──┬──► TP4056 ──► Battery (Li-Ion)
              │
              └──► AP2112K-3.3 ──► 3.3V ──► ESP32

ESP32 ──► OLED Display (I2C)
       ──► Servo Motor (PWM)
       ──► Buzzer (Audio)
       ──► LEDs (Status)
       ──► Buttons (User Input)
```

## Component Placement Zones
```
+------------------------+----------------------+
|      POWER ZONE        |     ESP32 ZONE      |
|   (Top-Left 30x25mm)  |  (Top-Right 30x25mm)|
|                        |                      |
|  USB-C  TP4056  LDO    |  ESP32-S3-WROOM-1  |
|  Battery  Schottky     |  Keepout Area       |
|  Power Caps            |  Bypass Caps        |
+------------------------+----------------------+
|      UI ZONE           |    OUTPUT ZONE      |
|   (Bottom-Left 30x25mm)| (Bottom-Right 30x25)|
|                        |                      |
|  Buttons  LEDs         |  OLED Connector     |
|  Status LEDs           |  Servo Connector    |
|  Buzzer                |                     |
+------------------------+----------------------+
```

## Component List

### Power Section
| Ref | Component | Value | Footprint |
|-----|---|---|---|
| J1 | USB-C | USB-C | USB_C_Receptacle_USB2.0_16P |
| U3 | TP4056 | Li-Ion Charger | SOIC-8 |
| U4 | AP2112K-3.3 | 3.3V LDO | SOT-23-5 |
| D3 | 1N5819 | Schottky Diode | SMA |
| J4 | Battery | JST 2-pin | Conn_01x02 |
| C10 | Capacitor | 100µF | Capacitor_THT |
| C1 | Capacitor | 10µF | 0805 |
| C2 | Capacitor | 10µF | 0805 |
| R11 | Resistor | 5.1kΩ | 0603 |
| R12 | Resistor | 5.1kΩ | 0603 |

### MCU Section  
| Ref | Component | Value | Footprint |
|-----|---|---|---|
| U1 | ESP32-S3-WROOM-1 | MCU Module | RF_Module |
| C5 | Capacitor | 100nF | 0603 |
| C6 | Capacitor | 100nF | 0603 |
| C7 | Capacitor | 100nF | 0603 |
| C8 | Capacitor | 100nF | 0603 |
| C9 | Capacitor | 10µF | 0805 |
| R8 | Resistor | 10kΩ | 0603 |
| R17 | Resistor | 10kΩ | 0603 |
| SW2 | Button | RESET | SW_Push |
| SW3 | Button | BOOT | SW_Push |

### UI Section
| Ref | Component | Value | Footprint |
|-----|---|---|---|
| SW1 | Button | USER | SW_Push |
| D1 | LED | Red (Status) | 0805 |
| D4 | LED | Red (Charge) | 0805 |
| D5 | LED | Green (Standby) | 0805 |
| BZ1 | Buzzer | 12x9.5mm | SMD |
| Q1 | MMBT2222A | NPN Transistor | SOT-23 |
| R1 | Resistor | 330Ω | 0603 |
| R2 | Resistor | 330Ω | 0603 |
| R3 | Resistor | 330Ω | 0603 |
| R4 | Resistor | 1kΩ | 0603 |

### Output Section
| Ref | Component | Value | Footprint |
|-----|---|---|---|
| J3 | OLED | 4-pin | Conn_01x04 |
| J2 | Servo | 3-pin | Conn_01x03 |
| R6 | Resistor | 4.7kΩ | 0603 |
| R7 | Resistor | 4.7kΩ | 0603 |
| R9 | Resistor | 100kΩ | 0603 |
| R10 | Resistor | 100kΩ | 0603 |

## GPIO Assignments
| GPIO | Function |
|---|---|
| GPIO0 | BOOT Button |
| GPIO4 | I2C SDA (OLED) |
| GPIO5 | I2C SCL (OLED) |
| GPIO9 | Servo PWM |
| GPIO10 | Buzzer |
| GPIO11 | Status LED |
| GPIO12 | User Button |
| GPIO34 | Battery ADC |

## Design Rules (JLCPCB)
- Min trace width: 0.127mm (5mil)
- Min clearance: 0.127mm
- Min via drill: 0.3mm
- Min via diameter: 0.6mm
- Copper pour clearance: 0.2mm

## Acceptance Criteria
- [ ] Schematic complete with all connections
- [ ] ERC: 0 errors
- [ ] PCB: 70x50mm
- [ ] Proper component placement by zone
- [ ] DRC: 0 errors
- [ ] Ground planes on both layers
- [ ] Gerbers generated

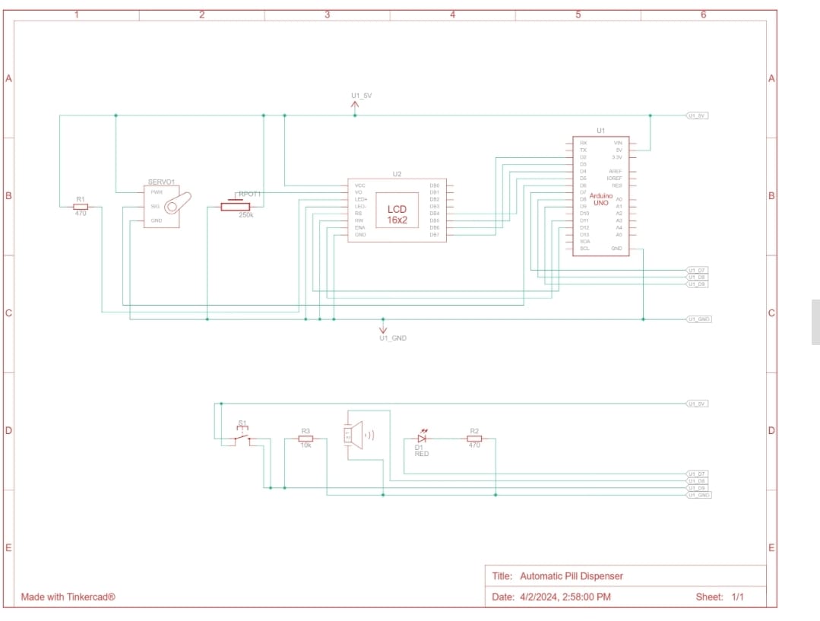
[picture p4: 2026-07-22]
board-photo-1.jpeg

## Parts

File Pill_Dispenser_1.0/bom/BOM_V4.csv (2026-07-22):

value | footprint | quantity | references
MMBT2222A | Package_TO_SOT_SMD:SOT-23 | 1 | ['Q1']
1k | Resistor_SMD:R_0603_1608Metric | 1 | ['R4']
10k | Resistor_SMD:R_0603_1608Metric | 2 | ['R17', 'R8']
22 | Resistor_SMD:R_0603_1608Metric | 2 | ['R15', 'R16']
ESP32-S3-WROOM-1 | RF_Module:ESP32-S3-WROOM-1 | 1 | ['U1']
STDBY | LED_SMD:LED_0603_1608Metric | 1 | ['D5']
1N5819 | Diode_SMD:D_SMA | 1 | ['D3']
USER | Button_Switch_SMD:SW_SPST_EVQP0 | 1 | ['SW1']
330 | Resistor_SMD:R_0603_1608Metric | 3 | ['R1', 'R2', 'R13']
STATUS | LED_SMD:LED_0603_1608Metric | 1 | ['D1']
TP4056-42-ESOP8 | Package_SO:SOIC-8-1EP_3.9x4.9mm_P1.27mm_EP2.41x3.3mm_ThermalVias | 1 | ['U3']
BATTERY | Connector_JST:JST_PH_B2B-PH-K_1x02_P2.00mm_Vertical | 1 | ['J4']
BOOT | Button_Switch_SMD:SW_SPST_EVQP0 | 1 | ['SW2']
CHRG | LED_SMD:LED_0603_1608Metric | 1 | ['D4']
4.7k | Resistor_SMD:R_0603_1608Metric | 2 | ['R7', 'R6']
OLED | Connector_PinHeader_2.54mm:PinHeader_1x04_P2.54mm_Vertical | 1 | ['J3']
100nF | Capacitor_SMD:C_0603_1608Metric | 4 | ['C5', 'C6', 'C8', 'C7']
10uF | Capacitor_SMD:C_0603_1608Metric | 3 | ['C2', 'C9', 'C1']
5.1k | Resistor_SMD:R_0603_1608Metric | 2 | ['R11', 'R12']
100k | Resistor_SMD:R_0603_1608Metric | 2 | ['R10', 'R9']
2k | Resistor_SMD:R_0603_1608Metric | 1 | ['R5']
Buzzer | Buzzer_Beeper:MagneticBuzzer_Kingstate_KCG0601 | 1 | ['BZ1']
RESET | Button_Switch_SMD:SW_SPST_EVQP0 | 1 | ['SW3']
USB-C | Connector_USB:USB_C_Receptacle_GCT_USB4135-GF-A_6P_TopMnt_Horizontal | 1 | ['J1']
100uF | Capacitor_SMD:CP_Elec_6.3x5.4 | 1 | ['C10']
AP2112K-3.3 | Package_TO_SOT_SMD:SOT-23-5 | 1 | ['U4']
SERVO | Connector_PinHeader_2.54mm:PinHeader_1x03_P2.54mm_Vertical | 1 | ['J2']

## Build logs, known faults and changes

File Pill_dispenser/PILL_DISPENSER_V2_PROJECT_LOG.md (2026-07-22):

# Pill Dispenser V2 — Complete Project Log

> **KiCad Version:** 9.0.7  
> **Last active PCB edit:** 2026-03-11  
> **Last active Schematic edit:** 2026-03-06  
> **Documentation generated:** 2026-03-15  
> **Project path:** `D:\UPES\Projects\Pill Despensor\Pill_dispenser\`

---

## Table of Contents

1. [Project Overview](#1-project-overview)
2. [File Inventory](#2-file-inventory)
3. [Bill of Materials (BOM)](#3-bill-of-materials-bom)
4. [PCB Footprint Map](#4-pcb-footprint-map)
5. [Schematic Issues & Fix History](#5-schematic-issues--fix-history)
6. [PCB DRC History & Error Progression](#6-pcb-drc-history--error-progression)
7. [Remaining Open Items](#7-remaining-open-items)
8. [MCP Server Setup](#8-mcp-server-setup)
9. [KiCad Python Backend](#9-kicad-python-backend)
10. [Summary of Current State](#10-summary-of-current-state)

---

## 1. Project Overview

**Pill Dispenser V2** is an ESP32-S3-based medication dispenser controller board designed as a PCB. The board handles:

- **Battery management** — USB-C charging via TP4056, Li-Ion battery input via JST PH connector.
- **Power regulation** — AP2112K-3.3 3.3 V LDO (primary), AMS1117-3.3 (backup/extended load).
- **Microcontroller** — ESP32-S3 module for BLE/Wi-Fi, pill scheduling logic, and motor control.
- **User interface** — 3× momentary push buttons (BOOT, RESET, USER), 1× SPDT power switch, 3× status LEDs, 1× buzzer.
- **Peripheral connectors** — OLED display (4-pin header), servo motor output (3-pin header), battery connector (JST PH 2-pin).
- **Status indication** — Red CHG LED (D4), Green STDBY LED (D5), Red STATUS LED (D1).

---

## 2. File Inventory

### Core Project Files

| File | Size | Last Modified | Description |
|---|---|---|---|
| `Pill_Dispenser_V2.kicad_sch` | ~170 KB | 2026-03-06 | Schematic — components, nets, lib_symbols |
| `Pill_Dispenser_V2.kicad_pcb` | ~243 KB | 2026-03-11 | PCB layout — footprints, traces, DRC rules |
| `Pill_Dispenser_V2.kicad_pro` | small | 2026-03-11 | Project settings file |
| `Pill_Dispenser_V2.kicad_prl` | small | 2026-03-11 | Local project settings (DRC severities, etc.) |

### DRC Report Files (Chronological)

| File | Timestamp | Unconnected | Violations | Notes |
|---|---|---|---|---|
| `Pill_Dispenser_V2_drc_violations.json` | 2026-03-11 00:57 | 12 | 64 | First full DRC run — silk errors, outline errors |
| `kicad_drc_report.json` | 2026-03-11 00:58 | 12 | 53 | After initial cleanup |
| `kicad_drc_report_final.json` | 2026-03-11 01:09 | 12 | 26 | Silk/drill violations cleared |
| `kicad_drc_report_final2.json` | 2026-03-11 01:10 | 12 | 26 | No change from final |
| `kicad_drc_report_final3.json` | 2026-03-11 01:11 | 12 | 26 | No change |
| `kicad_drc_report_final_check.json` | 2026-03-11 01:15 | 12 | 26 | Contains outline/drill errors |
| `final_verification.json` | 2026-03-11 01:16 | **0** | **26** | ✅ Unconnected resolved — all remaining are lib_footprint_mismatch warnings |

### Schematic Fix Scripts (Chronological)

| File | Purpose | Outcome |
|---|---|---|
| `fix_schematic.py` | Initial attempt — no-op rename on USBLC6-2SC6 | Ineffective |
| `fix_schematic2.py` | Regex removal of USBLC6-2SC6 / USBLC6-2P6 | Aggressive; risk of partial removal |
| `fix_schematic3.py` | Remove `(extends "USBLC6-2P6")` clause; rename parent to DummyName | Partial fix — DummyName still problem |
| `fix_schematic4.py` | Remove entire `(symbol "Power_Protection:USBLC6-2SC6" ...)` block | Removed broken symbol block |
| `fix_schematic5.py` | Remove orphan lib symbol blocks with extends referencing missing parents | Cleaned orphan extends |
| `fix_extends.py` | Rewrite AP2112K-3.3 and MMBT2222A extends as self-contained copied sub-symbols | Fixed broken extends chains |
| `fix_final.py` | Remove DummyName symbol block | Final cleanup |
| `diagnose.py` | Check for USBLC6, DummyName, extends references and parenthesis balance | Diagnostic / verification |

### Footprint / Component Verification Scripts

| File | Purpose |
|---|---|
| `check_footprints.py` | List all footprints in PCB and validate against schematic |
| `check_missing_fp.py` | Identify components with missing / blank footprint assignments |
| `list_fps.py` | Dump all footprints used in the PCB |
| `get_components.py` | Extract component reference + value + footprint from schematic |
| `fps_output.txt` | Output log from footprint verification scripts |

### Backup

| File | Date | Contents |
|---|---|---|
| `Pill_Dispenser_V2-backups/Pill_Dispenser_V2-2026-03-06_032009.zip` | 2026-03-06 | 242 entries — KiCAD-MCP-Server source + 4 KiCad project files (older than final PCB state) |

### Support Tools

| File/Folder | Description |
|---|---|
| `KiCAD-MCP-Server/` | Local KiCad MCP server v2.1.0-alpha (TypeScript/Node.js) |
| `KiCAD-MCP-Server/scripts/mcp-connection-check.mjs` | MCP protocol handshake test script (created during this session) |
| `KiCAD-MCP-Server/config/claude-desktop-config.json` | Active MCP client config (kicad + stitch servers) |

---

## 3. Bill of Materials (BOM)

### Power Section

| Ref | Value | Symbol | Footprint |
|-----|---|---|---|
| J1 | USB-C | `Connector_USB:USB_C_Receptacle_HRO_TYPE-C-31-M-12` | `USB_C_Receptacle_HRO_TYPE-C-31-M-12` |
| U3 | TP4056 | `Battery_Management:TP4056-42-ESOP8` | `SOIC-8_3.9x4.9mm_P1.27mm` |
| U4 | AP2112K-3.3 | `Regulator_Linear:AP2112K-3.3` | `SOT-23-5` |
| U2 | AMS1117-3.3 | `Regulator_Linear:AMS1117-3.3` | *(in schematic, verify footprint)* |
| D3 | 1N5819 (Schottky) | `Device:D_Schottky` | `D_SMA` |
| J4 | Battery | `Connector_JST:JST_PH_B2B-PH-K_1x02_P2.00mm_Vertical` | JST PH 2-pin |
| C10 | 470 µF | `Device:C_Polarized` | `CP_Radial_D8.0mm_P3.50mm` |
| C1 | 10 µF | `Device:C` | `C_0805_2012Metric` |
| C2 | 10 µF | `Device:C` | `C_0805_2012Metric` |
| C3 | 10 µF | `Device:C` | `C_0805_2012Metric` |
| C4 | 22 µF | `Device:C` | `C_0805_2012Metric` |
| C8 | 10 µF | `Device:C` | `C_0805_2012Metric` |
| R5 | 2 KΩ | `Device:R` | `R_0603_1608Metric` |
| R11 | 5.1 KΩ | `Device:R` | `R_0603_1608Metric` |
| R12 | 5.1 KΩ | `Device:R` | `R_0603_1608Metric` |
| R15 | 22 Ω | `Device:R` | `R_0603_1608Metric` |
| R16 | 22 Ω | `Device:R` | `R_0603_1608Metric` |
| SW4 | PWR_SW (SPDT) | `Switch:SW_SPDT` | `SW_E-Switch_EG1224_SPDT_Angled` |

### Microcontroller

| Ref | Value | Symbol | Footprint | ⚠️ Note |
|-----|---|---|---|---|
| U1 | ESP32-S3-MINI-1 | `RF_Module:ESP32-S3-MINI-1` | `RF_Module:ESP32-S3-WROOM-1` | **MISMATCH** — schematic symbol is MINI-1 but PCB footprint is WROOM-1 |
| C5 | 100 nF | `Device:C` | `C_0603_1608Metric` |  |
| C6 | 100 nF | `Device:C` | `C_0603_1608Metric` |  |
| C7 | 1 µF | `Device:C` | `C_0603_1608Metric` |  |
| C9 | 100 nF | `Device:C` | `C_0603_1608Metric` |  |
| R8 | 10 KΩ | `Device:R` | `R_0603_1608Metric` | BOOT pull-up |
| R17 | 10 KΩ | `Device:R` | `R_0603_1608Metric` | EN pull-up |
| SW2 | BOOT | `Switch:SW_Push` | `SW_PUSH_6mm_H5mm` |  |
| SW3 | RESET | `Switch:SW_Push` | `SW_PUSH_6mm_H5mm` |  |

### User Interface

| Ref | Value | Symbol | Footprint | Role |
|-----|---|---|---|---|
| SW1 | USER | `Switch:SW_Push` | `SW_PUSH_6mm_H5mm` | User input button |
| BZ1 | Buzzer | `Device:Buzzer` | `Buzzer_12x9.5RM7.6` | Audio alert |
| D1 | Red_STATUS | `Device:LED` | `LED_0805_2012Metric` | General status LED |
| D4 | Red_CHG | `Device:LED` | `LED_0805_2012Metric` | TP4056 CHRG indicator |
| D5 | Green_STDBY | `Device:LED` | `LED_0805_2012Metric` | TP4056 STDBY indicator |
| R1 | 100 Ω | `Device:R` | `R_0603_1608Metric` | LED current limit |
| R2 | 470 Ω | `Device:R` | `R_0603_1608Metric` | LED current limit |
| R13 | 1 KΩ | `Device:R` | `R_0603_1608Metric` | LED current limit |
| R14 | 1 KΩ | `Device:R` | `R_0603_1608Metric` | LED current limit |
| Q1 | MMBT2222A (NPN) | `Transistor_BJT:MMBT2222A` | `SOT-23` | Buzzer/LED driver |

### Peripheral Connectors

| Ref | Value | Symbol | Footprint | Connected to |
|-----|---|---|---|---|
| J2 | SERVO | `Connector_PinHeader_2.54mm:PinHeader_1x03` | `PinHeader_1x03_P2.54mm_Vertical` | Servo motor (PWM) |
| J3 | OLED | `Connector_PinHeader_2.54mm:PinHeader_1x04` | `PinHeader_1x04_P2.54mm_Vertical` | I2C OLED display |

### Support Passives

| Ref | Value | Footprint | Notes |
|-----|---|---|---|
| R3 | 10 KΩ | `R_0603_1608Metric` | Pull-up/down |
| R4 | 1 KΩ | `R_0603_1608Metric` | Base resistor (Q1 or LED) |
| R6 | 4.7 KΩ | `R_0603_1608Metric` | I2C pull-up (SDA) |
| R7 | 4.7 KΩ | `R_0603_1608Metric` | I2C pull-up (SCL) |
| R9 | 100 KΩ | `R_0603_1608Metric` | Voltage divider / bias |
| R10 | 100 KΩ | `R_0603_1608Metric` | Voltage divider / bias |

---

## 4. PCB Footprint Map

Total footprint count by package:

| Package | Count | Components |
|---|---|---|
| `R_0603_1608Metric` | 17 | R1–R17 |
| `C_0805_2012Metric` | 5 | C1–C4, C8 |
| `C_0603_1608Metric` | 4 | C5–C7, C9 |
| `SW_PUSH_6mm_H5mm` | 3 | SW1, SW2, SW3 |
| `LED_0805_2012Metric` | 3 | D1, D4, D5 |
| `SOT-23-5` | 1 | U4 (AP2112K-3.3) |
| `SOT-23` | 1 | Q1 (MMBT2222A) |
| `SOIC-8` | 1 | U3 (TP4056) |
| `D_SMA` | 1 | D3 (1N5819) |
| `PinHeader_1x04_P2.54mm` | 1 | J3 (OLED) |
| `PinHeader_1x03_P2.54mm` | 1 | J2 (SERVO) |
| `JST_PH_B2B` | 1 | J4 (Battery) |
| `CP_Radial_D8.0mm_P3.50mm` | 1 | C10 (470µF) |
| `Buzzer_12x9.5RM7.6` | 1 | BZ1 |
| `USB_C_Receptacle_HRO_TYPE-C-31-M-12` | 1 | J1 |
| `ESP32-S3-WROOM-1` | 1 | U1 |
| `SW_E-Switch_EG1224_SPDT_Angled` | 1 | SW4 (PWR) |

**Total footprints: ~43**

---

## 5. Schematic Issues & Fix History

### Root Cause

The schematic's embedded `lib_symbols` section contained several symbol definitions using the `(extends "ParentName")` KiCad syntax — but the referenced parent symbols either:
1. Did not exist in the embedded library, or  
2. Were themselves broken orphan entries.

This caused KiCad to fail to load the schematic cleanly and was the root cause of all earlier DRC "symbol not found" errors.

---

### Issue 1 — `USBLC6-2SC6` broken extends chain

**Symptom:** Symbol `Power_Protection:USBLC6-2SC6` had `(extends "USBLC6-2P6")` but `USBLC6-2P6` was not present in the embedded lib_symbols.

**Progression of fixes:**

```
fix_schematic.py   → No-op replacement; file unchanged; issue persisted
fix_schematic2.py  → Aggressive regex delete; risk of corrupt block removal
fix_schematic3.py  → Removed (extends "USBLC6-2P6") clause; renamed parent to "DummyName"
fix_schematic4.py  → Removed entire (symbol "Power_Protection:USBLC6-2SC6" ...) block
fix_schematic5.py  → Removed orphan lib symbols with extends referencing missing parents
```

**Resolution:** `fix_schematic5.py` successfully removed the broken USBLC6 and DummyName blocks from lib_symbols.

---

### Issue 2 — `AP2112K-3.3` and `MMBT2222A` broken extends

**Symptom:** Both symbols used extends to derive from a parent, but the parent sub-symbols were missing from the embedded definition, causing empty/broken symbol rendering.

**Fix:** `fix_extends.py` — rewrote both symbols as fully self-contained definitions by copying sub-symbol pin/body data from the parent symbol (or known correct reference).

**Resolution:** Both symbols now render correctly in schematic without needing any parent.

---

### Issue 3 — `DummyName` orphan block

**Symptom:** After fix_schematic3.py renamed `USBLC6-2P6` to `DummyName`, a `DummyName` lib symbol block remained in the schematic with no instances referencing it.

**Fix:** `fix_final.py` — located and removed the entire `(symbol "DummyName" ...)` block.

**Resolution:** Clean schematic with no orphan lib_symbol entries.

---

### Current Schematic State (as of 2026-03-06)

- ✅ No broken extends references  
- ✅ No orphaned lib_symbol blocks (USBLC6-2SC6, USBLC6-2P6, DummyName all removed)  
- ✅ AP2112K-3.3 self-contained  
- ✅ MMBT2222A self-contained  
- ⚠️ U1 symbol mismatch: schematic uses `RF_Module:ESP32-S3-MINI-1` but PCB footprint is `RF_Module:ESP32-S3-WROOM-1` (see open items)

---

## 6. PCB DRC History & Error Progression

### Run 1 — `Pill_Dispenser_V2_drc_violations.json` (2026-03-11 00:57)

**Total: 64 violations — 13 errors, 51 warnings**

| Type | Count | Description |
|---|---|---|
| `drill_out_of_range` | 12 | Hole diameter 0.2 mm below minimum 0.3 mm — affected USB-C shield pads |
| `invalid_outline` | 1 | No edges found on `Edge.Cuts` layer — board outline missing |
| `silk_over_copper` | 25 | Silkscreen text overlapping copper pads |
| `silk_overlap` | 26 | Silkscreen items overlapping each other |

---

### Runs 2–4 — After silk/copper cleanup (2026-03-11 00:58–01:11)

**Violations: 26 | Unconnected: 12**

Silk violations cleared. Remaining 26 violations were all `lib_footprint_mismatch` warnings.

Unconnected items at this stage:

| Ref | Pads Unconnected |
|-----|---|
| J1 (USB-C) | A1/B1 (GND), A4/A9 (VBUS), S1/S2 (shield) |
| SW2 (BOOT) | Pad1, Pad2 |
| SW3 (RESET) | Pad1, Pad2 |
| SW4 (PWR) | Pad1, Pad2 |

> **Note:** The `invalid_outline` (no Edge.Cuts) from Run 1 does not appear in the violations array in runs 2–4 — it may have been excluded from the count via DRC severity settings in `.kicad_prl`.

---

### Run 7 — `final_verification.json` ✅ (2026-03-11 01:16:02)

**This is the authoritative final DRC state.**

```
Date         : 2026-03-11T01:16:02+0530
KiCad Version: 9.0.7
Source       : Pill_Dispenser_V2.kicad_pcb
Unconnected  : 0   ✅
Violations   : 26  (all severity=warning, all type=lib_footprint_mismatch)
```

All 26 `lib_footprint_mismatch` warnings are because locally-edited footprints no longer match their counterparts in the KiCad system library. **These are non-blocking for fabrication.** They do not indicate electrical errors.

Components with `lib_footprint_mismatch` warnings:

| Ref | Footprint | Library |
|-----|---|---|
| R1, R2, R4–R9, R11–R16 | `R_0603_1608Metric` | `Resistor_SMD` |
| C1–C7 | `C_0605/0805_…Metric` | `Capacitor_SMD` |
| D3 | `D_SMA` | `Diode_SMD` |
| D1, D4, D5 | `LED_0805_2012Metric` | `LED_SMD` |
| J1 | `USB_C_Receptacle_HRO_TYPE-C-31-M-12` | `Connector_USB` |
| SW2/SW4 | push/SPDT switch footprints | `Button_Switch_THT` |

**To fix:** Run PCB Editor → Tools → Update Footprints from Library and accept the refresh.  
**To ignore officially:** Add each to DRC exclusions in `.kicad_prl`.

---

## 7. Remaining Open Items

### 🔴 High Priority

#### 1. ESP32 Module Mismatch (U1)

| Property | Value |
|---|---|
| Schematic symbol | `RF_Module:ESP32-S3-MINI-1` |
| PCB footprint | `RF_Module:ESP32-S3-WROOM-1` |
| Impact | Module pin-out and dimensions differ between MINI-1 and WROOM-1 |
| Status | Unresolved — **must be verified before ordering boards or modules** |

**Action required:** Confirm which physical module is actually being used and ensure schematic symbol, netlist, and PCB footprint all agree.

- ESP32-S3-MINI-1: 27 mm × 34.3 mm, FCC/CE certified
- ESP32-S3-WROOM-1: 18 mm × 20 mm, smaller form factor

---

### 🟡 Medium Priority

#### 2. Board Outline Missing (`Edge.Cuts`)

First DRC run (`Pill_Dispenser_V2_drc_violations.json`) reported `invalid_outline: no edges found on Edge.Cuts layer`. This error is absent from later runs, likely suppressed via DRC severity settings rather than actually fixed.

**Action required:** Confirm `Edge.Cuts` layer contains a closed board outline. Without an outline, Gerber generation will fail.

---

#### 3. 26 `lib_footprint_mismatch` Warnings

Non-blocking but noisy. Will appear in every DRC run until resolved.

**Action required:** Either:
- Update footprints from library (PCB Editor → Tools → Update Footprints from Library), or  
- Add to DRC exclusions list to formally acknowledge them.

---

#### 4. Drill Out of Range (USB-C shield pads)

First DRC run showed 12 `drill_out_of_range` errors (0.2 mm < 0.3 mm minimum). Not visible in later DRC files — may have been corrected or excluded.

**Action required:** Verify J1 (USB-C) shield pad drill sizes are ≥ 0.3 mm before sending Gerbers.

---

### 🟢 Already Resolved

| Issue | Resolution |
|---|---|
| Broken extends chains (`USBLC6-2SC6`, `AP2112K-3.3`, `MMBT2222A`) | fix_extends.py + fix_schematic*.py |
| DummyName orphan lib symbol | fix_final.py |
| Schematic wouldn't open cleanly | All extends fixed; file loads in KiCad 9.0.7 |
| 12 unconnected items | Resolved in final PCB layout pass (2026-03-11 01:16) |
| 38 extra DRC violations (silk, drill) | Cleared during PCB cleanup session |

---

## 8. MCP Server Setup

### Configuration File

**Location:** `KiCAD-MCP-Server/config/claude-desktop-config.json`

```json
{
  "mcpServers": {
    "kicad": {
      "command": "node",
      "args": [
        "D:\\UPES\\Projects\\Pill Despensor\\Pill_dispenser\\KiCAD-MCP-Server\\dist\\index.js"
      ],
      "env": {
        "PYTHONPATH": "C:\\Program Files\\KiCad\\9.0\\lib\\python3\\dist-packages",
        "LOG_LEVEL": "info"
      }
    },
    "stitch": {
      "serverUrl": "https://stitch.googleapis.com/mcp",
      "headers": {
        "X-Goog-Api-Key": "<redacted>"
      }
    }
  }
}
```

### Server Info

| Property | Value |
|---|---|
| Package | `kicad-mcp` v2.1.0-alpha |
| SDK | `@modelcontextprotocol/sdk` v1.21.0 |
| Transport | STDIO (newline-delimited JSON-RPC) |
| Entry point | `dist/index.js` |
| Python bridge | `python/kicad_interface.py` |
| Tools exposed | **99 tools** |

### Wire Protocol (Important)

The MCP SDK uses **newline-delimited JSON**, **not** HTTP `Content-Length` framing:

```js
// SDK serialize (from sdk/dist/esm/shared/stdio.js):
serializeMessage = (msg) => JSON.stringify(msg) + '\n';
// Parser splits on newline '\n', not Content-Length header
```

This was discovered when the initial MCP connection check script (which used Content-Length framing) failed with timeout. The script was updated to use newline-delimited JSON and then succeeded.

### Connection Test Results (2026-03-15)

```
MCP_INIT_OK: true
SERVER_NAME: kicad-mcp-server
SERVER_VERSION: 1.0.0
TOOLS_LIST_OK: true
TOOLS_COUNT: 99
Exit code: 0
```

**STDERR from server (healthy):**
```
[INFO] Using STDIO transport for local communication
[INFO] All KiCAD tools, resources, and prompts registered
[INFO] Router pattern enabled: 4 router tools + direct tools for discovery
[INFO] Found KiCAD bundled Python at: C:\Program Files\KiCad\9.0\bin\python.exe
[INFO] ✓ pcbnew module validated successfully
[INFO] Successfully connected to STDIO transport
KiCAD MCP SERVER READY
[INFO] Python version: 3.11.5 ... python executable: C:\Program Files\KiCad\9.0\bin\python.exe
```

---

## 9. KiCad Python Backend

| Property | Value |
|---|---|
| KiCad install | `C:\Program Files\KiCad\9.0\` |
| Python executable | `C:\Program Files\KiCad\9.0\bin\python.exe` |
| Python version | 3.11.5 |
| pcbnew module path | `C:\Program Files\KiCad\9.0\lib\python3\dist-packages` |
| pcbnew import | ✅ Validated successfully |

---

## 10. Summary of Current State

### What's Done ✅

| Task | Status |
|---|---|
| Schematic loads cleanly in KiCad 9.0.7 | ✅ |
| All broken `extends` references removed | ✅ |
| 0 unconnected items in PCB | ✅ |
| DRC violations down from 64 → 26 (all warnings) | ✅ |
| Silk overlap / silk-over-copper errors cleared | ✅ |
| MCP server config written and active | ✅ |
| MCP connection test passed (99 tools live) | ✅ |
| KiCad Python backend validated | ✅ |

### What Still Needs Attention ⚠️

| Task | Priority | Description |
|---|---|---|
| Verify ESP32 module selection | 🔴 High | MINI-1 vs WROOM-1 — decide and reconcile schematic + PCB |
| Add/verify board Edge.Cuts outline | 🔴 High | Required for Gerber export |
| Resolve or exclude 26 lib_footprint_mismatch | 🟡 Medium | Update from library OR add DRC exclusions |
| Verify USB-C shield pad drill sizes | 🟡 Medium | Confirm ≥ 0.3 mm for all J1 pads |
| Run full DRC after above fixes | 🟡 Medium | Confirm 0 errors and 0 unconnected post-reconciliation |
| ERC (Electrical Rules Check) on schematic | 🟡 Medium | Not verified — run before fab |
| Generate Gerbers + drill files | 🟢 Final | Only after all above items cleared |

---

*This file was auto-generated from project scan on 2026-03-15 using KiCad 9.0.7 file analysis and DRC report review.*

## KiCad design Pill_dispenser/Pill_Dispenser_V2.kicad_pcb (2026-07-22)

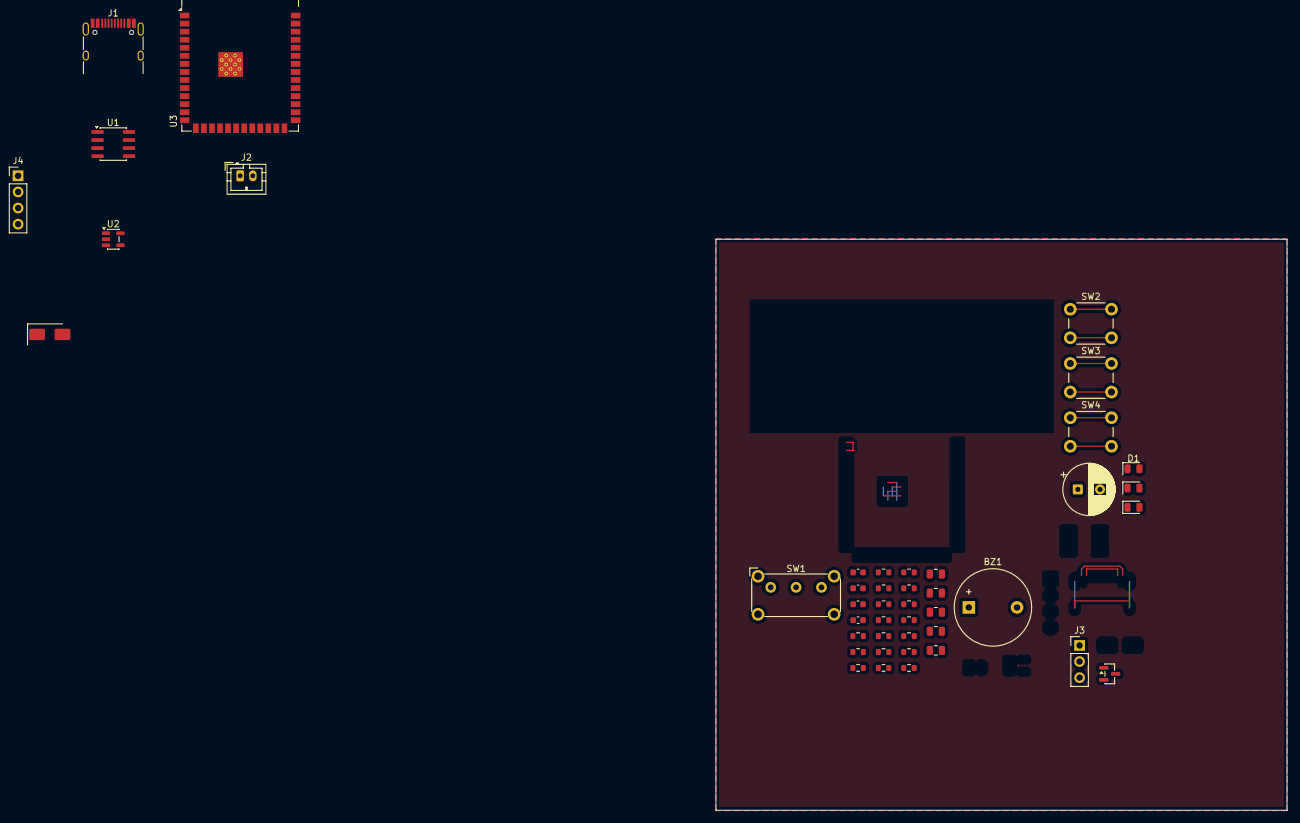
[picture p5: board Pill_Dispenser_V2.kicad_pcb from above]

Board: 2 copper layers, 90.0 x 90.0 mm, 44 parts (0 on the bottom side), 3 nets.

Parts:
BZ1: Buzzer; Buzzer_12x9.5RM7.6
C1, C3, C4, C9: 10uF; C_0805_2012Metric
C2, C6, C7: 100nF; C_0603_1608Metric
C5: 22uF; C_0805_2012Metric
C8: 1uF; C_0603_1608Metric
C10: 470uF; CP_Radial_D8.0mm_P3.50mm
D1: Red_CHG; LED_0805_2012Metric
D2: Green_STDBY; LED_0805_2012Metric
D3: 1N5819; D_SMA
D4: Red_STATUS; LED_0805_2012Metric
J1: USB-C; USB_C_Receptacle_HRO_TYPE-C-31-M-12
J2: Battery; JST_PH_B2B-PH-K_1x02_P2.00mm_Vertical
J3: SERVO; PinHeader_1x03_P2.54mm_Vertical
J4: OLED; PinHeader_1x04_P2.54mm_Vertical
Q1: MMBT2222A; SOT-23
R1, R2: 5.1K; R_0603_1608Metric
R3, R4: 22; R_0603_1608Metric
R5: 2K; R_0603_1608Metric
R6, R7, R13: 1K; R_0603_1608Metric
R8, R9, R17: 10K; R_0603_1608Metric
R10: 100; R_0603_1608Metric
R11, R12: 4.7K; R_0603_1608Metric
R14: 470; R_0603_1608Metric
R15, R16: 100K; R_0603_1608Metric
SW1: PWR_SW; SW_E-Switch_EG1224_SPDT_Angled
SW2: RESET; SW_PUSH_6mm_H5mm
SW3: BOOT; SW_PUSH_6mm_H5mm
SW4: USER; SW_PUSH_6mm_H5mm
U1: TP4056; SOIC-8_3.9x4.9mm_P1.27mm
U2: AP2112K-3.3; SOT-23-5
U3: ESP32-S3-MINI-1; ESP32-S3-WROOM-1

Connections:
unnamed: J1.A1 (GND), J1.A12 (GND), J1.B1 (GND), J1.B12 (GND)
unnamed: J1.A4 (VBUS), J1.A9 (VBUS), J1.B4 (VBUS), J1.B9 (VBUS)
unnamed: U3.1 (GND), U3.2 (GND)

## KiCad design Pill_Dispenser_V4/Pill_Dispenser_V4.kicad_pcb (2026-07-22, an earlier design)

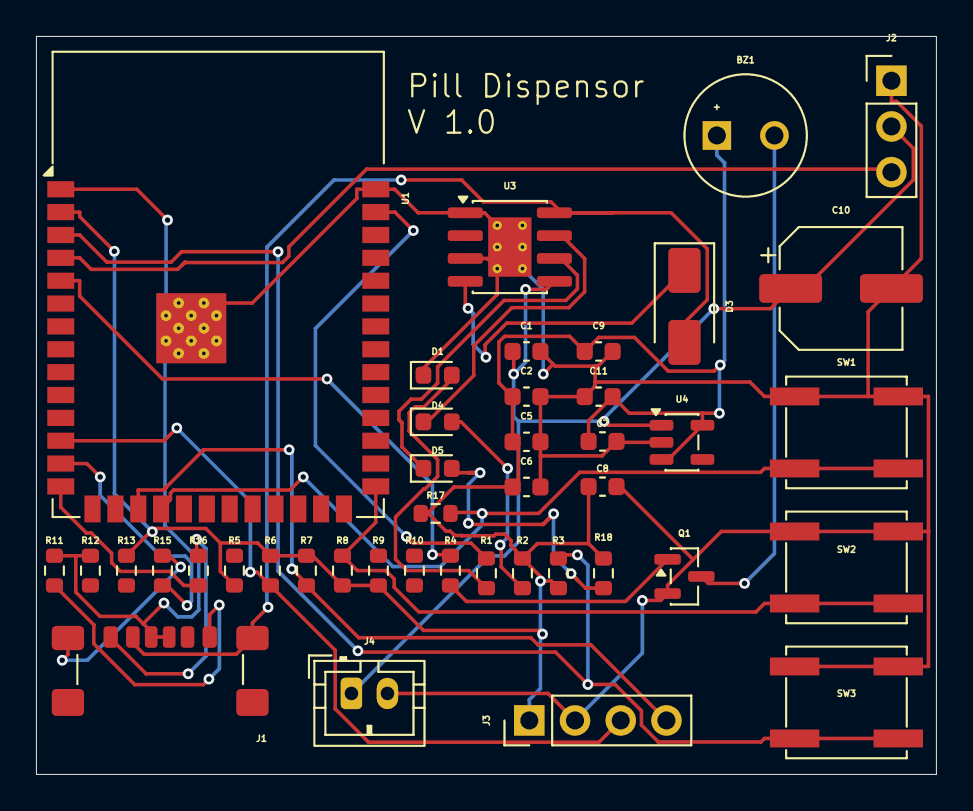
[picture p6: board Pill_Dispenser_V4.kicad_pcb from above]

Board: 2 copper layers, 50.0 x 41.0 mm, 42 parts (0 on the bottom side), 25 nets.

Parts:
BZ1: Buzzer; MagneticBuzzer_Kingstate_KCG0601
C1, C2, C9: 10uF; C_0603_1608Metric
C5, C6, C7, C8, C11: 100nF; C_0603_1608Metric
C10: 100uF; CP_Elec_6.3x5.4
D1: STATUS; LED_0603_1608Metric
D3: 1N5819; D_SMA
D4: CHRG; LED_0603_1608Metric
D5: STDBY; LED_0603_1608Metric
J1: USB-C; USB_C_Receptacle_GCT_USB4135-GF-A_6P_TopMnt_Horizontal
J2: SERVO; PinHeader_1x03_P2.54mm_Vertical
J3: OLED; PinHeader_1x04_P2.54mm_Vertical
J4: BATTERY; JST_PH_B2B-PH-K_1x02_P2.00mm_Vertical
Q1: MMBT2222A; SOT-23
R1, R13: 330; R_0603_1608Metric
R2, R4, R18: 1k; R_0603_1608Metric
R3, R8, R17: 10k; R_0603_1608Metric
R5: 2k; R_0603_1608Metric
R6, R7: 4.7k; R_0603_1608Metric
R9, R10: 100k; R_0603_1608Metric
R11, R12: 5.1k; R_0603_1608Metric
R15, R16: 22; R_0603_1608Metric
SW1: USER; SW_SPST_EVQP0
SW2: BOOT; SW_SPST_EVQP0
SW3: RESET; SW_SPST_EVQP0
U1: ESP32-S3-WROOM-1
U3: TP4056-42-ESOP8; SOIC-8-1EP_3.9x4.9mm_P1.27mm_EP2.41x3.3mm_ThermalVias
U4: AP2112K-3.3; SOT-23-5

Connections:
/3V3: BZ1.1 (+), C2.1, C5.1, C6.1, C7.1, C8.1, C9.1, C11.2, J3.1, R2.2, R3.1, R5.1, R6.2, R7.2, R8.1, R9.1, R13.2, R17.2, R18.2, U1.2 (3V3), U4.3 (EN), U4.5 (VOUT)
/CHRG: D4.1 (K), U3.7 (~CHRG)
/SCL: J3.4, R7.1, U1.17 (IO9)
/SDA: J3.3, R6.1, U1.12 (IO8)
/STATUS: R1.2, U1.39 (IO1)
/STDBY: D5.1 (K), U3.6 (~STDBY)
/USB_DN: J1.7, R15.2
/USB_DP: J1.6, R16.2
/VBAT: C1.1, C10.1, J2.2, J4.1, U3.5 (BAT), U4.1 (VIN)
/VBUS: D3.2 (A), J1.4, J1.9, U3.8 (CE)
GND: C1.2, C2.2, C5.2, C6.2, C7.2, C8.2, C9.2, C10.2, C11.1, D1.1 (K), J1.1, J1.2, J2.1, J3.2, J4.2, Q1.2 (C), R11.2, R12.2, SW1.1, SW2.1, SW3.1, U1.1 (GND), U1.40 (GND), U1.41 (GND), U3.1 (TEMP), U3.3 (GND), U3.9 (EPAD), U4.2 (GND)
unnamed: BZ1.2 (-), Q1.3 (E)
unnamed: D1.2 (A), R1.1
unnamed: D3.1 (K), U3.4 (V_{CC})
unnamed: D4.2 (A), R2.1
unnamed: D5.2 (A), R18.1
unnamed: J1.5, R11.1
unnamed: J2.3, U1.4 (IO4)
unnamed: Q1.1 (B), R4.1
unnamed: R3.2, SW3.2, U1.3 (EN)
unnamed: R8.2, SW2.2, U1.27 (IO0)
unnamed: R4.2, U1.5 (IO5)
unnamed: R17.1, SW1.2, U1.18 (IO10)
unnamed: R16.1, U1.14 (USB_D+)
unnamed: R15.1, U1.13 (USB_D-)

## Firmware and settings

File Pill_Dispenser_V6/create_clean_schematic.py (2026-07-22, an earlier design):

#!/usr/bin/env python3
"""
Generate clean Pill Dispenser V6 KiCad schematic with proper wire format.
"""

def gen_schematic():
    # Wire definitions with proper coordinates
    wires = [
        # VBUS - USB to TP4056
        {'pts': [(39.84, 102.54), (60.16, 102.54)], 'uuid': 'w0001'},
        {'pts': [(39.84, 102.54), (42.38, 69.92)], 'uuid': 'w0002'},
        {'pts': [(42.38, 69.92), (57.62, 72.46)], 'uuid': 'w0003'},
        # GND - USB to TP4056
        {'pts': [(39.84, 100), (60.16, 100)], 'uuid': 'w0004'},
        {'pts': [(39.84, 100), (42.38, 72.46)], 'uuid': 'w0005'},
        # TP4056 GND to LDO GND
        {'pts': [(42.38, 72.46), (50, 44.92)], 'uuid': 'w0006'},
        # LDO input from Schottky
        {'pts': [(70, 94.92), (44.92, 50)], 'uuid': 'w0007'},
        # LDO output to ESP32
        {'pts': [(50, 55.08), (122.22, 85.24)], 'uuid': 'w0008'},
        # Battery path
        {'pts': [(57.62, 69.92), (70, 105.08)], 'uuid': 'w0009'},
        {'pts': [(70, 105.08), (30, 115.08)], 'uuid': 'w0010'},
    ]
    
    # Build wire S-expressions
    wire_block = []
    for w in wires:
        x1, y1 = w['pts'][0]
        x2, y2 = w['pts'][1]
        wire_block.append(f'    (wire (pts (xy {x1} {y1}) (xy {x2} {y2})) (uuid "{w["uuid"]}"))')
    
    wires_str = '\n'.join(wire_block)
    
    schematic = f'''(kicad_sch (version 20211117) (generator "Pill_Dispenser_V6")

  (uuid "a1b05787-cd6a-483e-afe0-48eda7657ffa")

  (paper "A4")

  (lib_symbols
    (symbol "power:+3.3V"
      (pin power_in line (at 0 0 270) (length 2.54) (name "+3V3") (number "1"))
      (rectangle (start -1.27 -1.27) (end 1.27 1.27) (stroke (width 0.254) (type default)) (fill (type background)))
    )
    (symbol "power:GND"
      (pin power_in line (at 0 0 270) (length 2.54) (name "GND") (number "1"))
      (rectangle (start -1.27 -1.27) (end 1.27 1.27) (stroke (width 0.254) (type default)) (fill (type background)))
      (polyline (pts (xy 0 0) (xy 0 1.27)) (stroke (width 0) (type default)) (fill (type none)))
      (polyline (pts (xy 0 1.27) (xy -1.27 3.81) (xy 1.27 3.81) (xy 0 1.27)) (stroke (width 0) (type default)) (fill (type none)))
    )
    (symbol "power:VBUS"
      (pin power_in line (at 0 0 270) (length 2.54) (name "VBUS") (number "1"))
      (rectangle (start -1.27 -1.27) (end 1.27 1.27) (stroke (width 0.254) (type default)) (fill (type background)))
    )
    (symbol "Device:R"
      (pin_numbers hide)
      (pin_names (offset 0))
      (in_bom yes)
      (on_board yes)
      (property "Reference" "R" (at 2.032 0 90) (effects (font (size 1.27 1.27))))
      (property "Value" "R" (at 0 0 90) (effects (font (size 1.27 1.27))))
      (property "Footprint" "Resistor_SMD:R_0603_1608Metric" (at 0 0 0) (effects (font (size 1.27 1.27)) hide))
      (symbol "R_0_1"
        (rectangle (start -1.016 -2.54) (end 1.016 2.54) (stroke (width 0.254) (type default)) (fill (type none)))
      )
      (symbol "R_1_1"
        (pin passive line (at 0 3.81 270) (length 1.27) (name "~") (number "1"))
        (pin passive line (at 0 -3.81 90) (length 1.27) (name "~") (number "2"))
      )
    )
    (symbol "Device:C"
      (pin_numbers hide)
      (pin_names (offset 0.254))
      (in_bom yes)
      (on_board yes)
      (property "Reference" "C" (at 0.635 2.54 0) (effects (font (size 1.27 1.27)) (justify left)))
      (property "Value" "C" (at 0.635 -2.54 0) (effects (font (size 1.27 1.27)) (justify left)))
      (symbol "C_0_1"
        (polyline (pts (xy -2.032 -0.762) (xy 2.032 -0.762)) (stroke (width 0.508) (type default)) (fill (type none)))
        (polyline (pts (xy -2.032 0.762) (xy 2.032 0.762)) (stroke (width 0.508) (type default)) (fill (type none)))
      )
      (symbol "C_1_1"
        (pin passive line (at 0 3.81 270) (length 2.54) (name "~") (number "1"))
        (pin passive line (at 0 -3.81 90) (length 2.54) (name "~") (number "2"))
      )
    )
    (symbol "Device:LED"
      (pin_numbers hide)
      (pin_names (offset 0))
      (in_bom yes)
      (on_board yes)
      (property "Reference" "D" (at 2.54 0 90) (effects (font (size 1.27 1.27))))
      (property "Value" "LED" (at 0 0 90) (effects (font (size 1.27 1.27))))
      (property "Footprint" "LED_SMD:LED_0805_2012Metric" (at 0 0 0) (effects (font (size 1.27 1.27)) hide))
      (symbol "LED_0_1"
        (polyline (pts (xy -1.27 -1.27) (xy -1.27 1.27)) (stroke (width 0.254) (type default)) (fill (type none)))
        (polyline (pts (xy -1.27 0) (xy 1.27 1.52)) (stroke (width 0.254) (type default)) (fill (type none)))
        (polyline (pts (xy -1.27 1.52) (xy 1.27 0)) (stroke (width 0.254) (type default)) (fill (type none)))
        (polyline (pts (xy 1.27 1.52) (xy 1.27 -1.52) (xy -1.27 -1.27) (xy 1.27 1.52)) (stroke (width 0.254) (type default)) (fill (type background)))
      )
      (symbol "LED_1_1"
        (pin passive line (at 0 5.08 270) (length 2.54) (name "K") (number "1"))
        (pin passive line (at 0 -5.08 90) (length 2.54) (name "A") (number "2"))
      )
    )
    (symbol "Device:D_Schottky"
      (pin_numbers hide)
      (pin_names (offset 0))
      (in_bom yes)
      (on_board yes)
      (property "Reference" "D" (at 2.54 0 90) (effects (font (size 1.27 1.27))))
      (property "Value" "D_Schottky" (at 0 0 90) (effects (font (size 1.27 1.27))))
      (symbol "D_Schottky_0_1"
        (polyline (pts (xy 0 2.54) (xy 0 -2.54)) (stroke (width 0.254) (type default)) (fill (type none)))
        (polyline (pts (xy -2.54 2.54) (xy -2.54 -2.54) (xy 2.54 0) (xy -2.54 2.54)) (stroke (width 0.254) (type default)) (fill (type background)))
      )
      (symbol "D_Schottky_1_1"
        (pin passive line (at 0 5.08 270) (length 2.54) (name "K") (number "1"))
        (pin passive line (at 0 -5.08 90) (length 2.54) (name "A") (number "2"))
      )
    )
    (symbol "Battery_Management:TP4056"
      (pin_numbers hide)
      (pin_names (offset 1.016))
      (in_bom yes)
      (on_board yes)
      (property "Reference" "U" (at 2.54 0 90) (effects (font (size 1.27 1.27))))
      (property "Value" "TP4056" (at 0 0 90) (effects (font (size 1.27 1.27))))
      (symbol "TP4056_1_1"
        (rectangle (start -5.08 -5.08) (end 5.08 5.08) (stroke (width 0.254) (type default)) (fill (type background)))
        (pin passive line (at -7.62 2.54 0) (length 2.54) (name "TEMP") (number "1"))
        (pin passive line (at -7.62 0 0) (length 2.54) (name "PROG") (number "2"))
        (pin passive line (at -7.62 -2.54 0) (length 2.54) (name "GND") (number "3"))
        (pin passive line (at -7.62 -5.08 0) (length 2.54) (name "VCC") (number "4"))
        (pin passive line (at 7.62 -5.08 180) (length 2.54) (name "BAT") (number "5"))
        (pin passive line (at 7.62 -2.54 180) (length 2.54) (name "VCC") (number "6"))
        (pin passive line (at 7.62 0 180) (length 2.54) (name "STBY") (number "7"))
        (pin passive line (at 7.62 2.54 180) (length 2.54) (name "CHRG") (number "8"))
      )
    )
    (symbol "Regulator_Linear:AP2112K-3.3"
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

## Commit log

2026-07-22 feat: Smart Pill Dispenser — KiCad hardware project (V1→V7, Gerbers, 3D STEP)
    [BOM_V4.csv, BOM_V4_final.csv, Pill_Dispenser_V2.kicad_pcb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]
2026-07-22 docs: add prototype→PCB visual showcase
